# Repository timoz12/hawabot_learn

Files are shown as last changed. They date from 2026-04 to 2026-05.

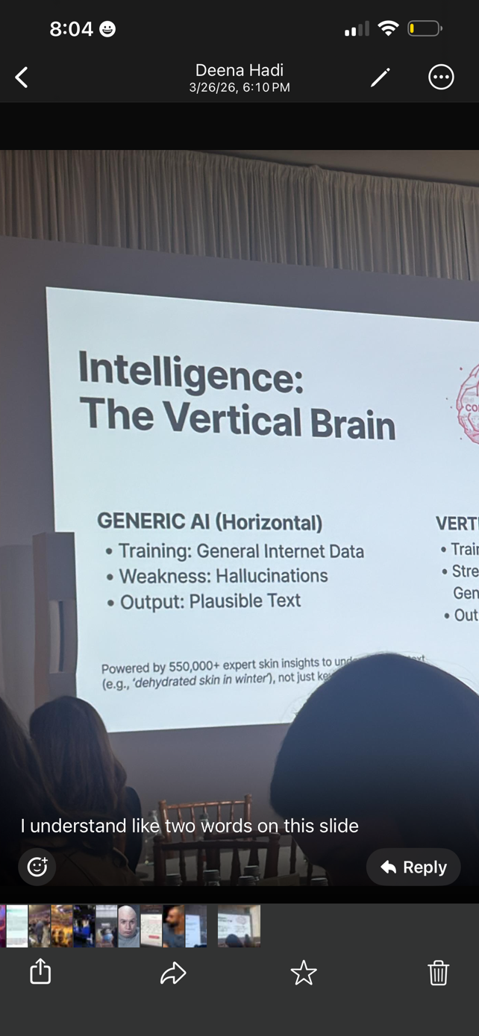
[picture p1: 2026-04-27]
docs/research/IMG_9037.PNG

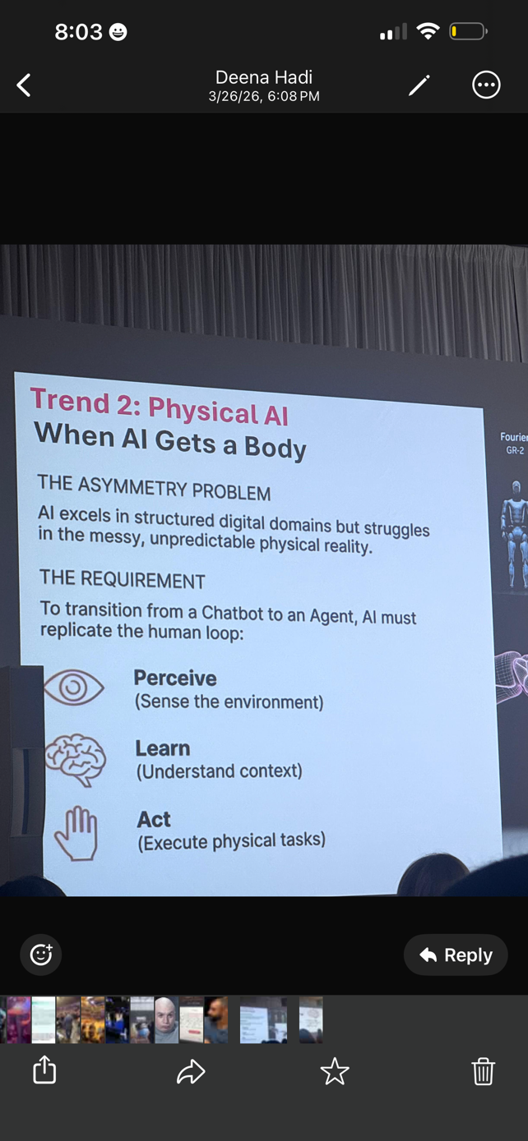
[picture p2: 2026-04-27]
docs/research/IMG_9034.PNG

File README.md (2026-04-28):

# HawaBot

Physical AI robotics platform for kids. Part of [Hawa Labs](https://hawalabs.com).

Kids design a custom robot character, Hawa Labs 3D prints and ships it, then kids code and teach their robot using Python + an AI tutor.

## Project Structure

```
hawabot/                      SDK — Python package shipped with every kit
├── robot.py                  Student entry point
├── character/                Character profiles + animations
├── config/                   Hardware tier definitions (Spark/Core/Pro)
├── joints/                   Body parts (head, arm, waist, leg)
├── drivers/                  Hardware abstraction (mock, pico, pi5)
├── sensors/                  Sensor abstractions
├── sim/                      Simulation engine + 2D visualizer
├── teach.py                  Teach-by-demo (record + playback)
├── curriculum/               Mission loader + progress tracker
├── tutor/                    AI tutor + safety filter
└── studio/                   Streamlit IDE

pipeline/                     Shell pipeline — the moat
├── skeleton.py               Spark skeleton geometry generator
├── shell_pipeline.py         Scale → Subtract → Trim → Validate
├── joint_cuts.py             Joint clearance cuts + section splitting
├── preview.py                3D preview renderer (matplotlib)
├── SKELETON_SPEC.md          Parametric SolidWorks reference
└── skeleton_exports/         SolidWorks parameter files + exported STLs

web/                          Design platform prototype
├── app.py                    Flask backend (Meshy API + pipeline)
└── templates/index.html      Three.js frontend

firmware/                     Microcontroller firmware
└── pico_w/main.py            MicroPython servo controller for Pi Pico W

missions/                     Curriculum content (5 months)
├── month_01/ ... month_05/

docs/                         Documentation
├── STRATEGY.md               Vision, moat, business model
├── COMPETITIVE_ANALYSIS.md   Feature matrix vs competitors
├── ARCHITECTURE.md           Technical architecture
├── IMPLEMENTATION_PLAN.md    Phased build plan
├── GO_TO_MARKET.md           GTM strategy
├── research/                 Original inspiration (slides, papers)
└── reference_robot/          Full-scale Hawabot specs (Poppy URDF, servos)
```

## Quick Start

```bash
python3 -m venv .venv
source .venv/bin/activate
pip install -e ".[sim]"
pip install flask trimesh manifold3d scipy shapely rtree
```

### Run the SDK
```python
from hawabot import Robot

robot = Robot()
robot.head.pan(45)
robot.arm.left.wave()
robot.express("happy")

recording = robot.teach(5)
robot.play(recording)
robot.shutdown()
```

### Run the Design Platform
```bash
python web/app.py
# Open http://localhost:5001
```

### Run the Shell Pipeline
```bash
python -m pipeline.shell_pipeline sculpture.stl skeleton.stl output_shell.stl
```

## Hardware Tiers

| Tier | Form | DOF | Voice | BOM | Price |
|---|---|-----|---|-----|---|
| **Spark** | Tabletop companion | 5 | Buzzer | ~$69 | $99 / $25mo |
| **Core** | Enhanced upper body | 10 | Mic + speaker | ~$200 | $249 / $55mo |
| **Pro** | Full bipedal | 21 | HQ mic + speaker | ~$400 | $499 / $110mo |

## Environment Variables

```bash
HAWABOT_MOCK=1             # Force simulation mode (default)
ANTHROPIC_API_KEY=sk-...   # Required for AI tutor
MESHY_API_KEY=...          # Required for real 3D generation
```

## Hardware Setup (Spark Tier)

To run on real hardware instead of simulation:

```bash
pip install pyserial        # Required for PicoDriver
```

1. Flash MicroPython onto Pi Pico W (hold BOOTSEL, drag `.uf2`)
2. Copy `firmware/pico_w/main.py` to the Pico W (via Thonny or mpremote)
3. Wire servos to GP0-GP4 (see `docs/ARCHITECTURE.md` for pin map)
4. Connect Pico W via USB

```python
from hawabot import Robot
robot = Robot(mock=False)   # Connects to Pico W on /dev/ttyACM0
robot.head.pan(45)          # Physical servo moves!
```

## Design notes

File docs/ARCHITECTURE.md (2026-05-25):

# HawaBot Technical Architecture

## System Overview

HawaBot is composed of five major subsystems that work together to deliver the full experience: design a character, manufacture the physical robot, code it, learn from it, and grow with it.

```
+---------------------+       +---------------------+       +---------------------+
|  DESIGN PLATFORM    |       |  SHELL PIPELINE     |       |  FULFILLMENT        |
|  (web/)             |  -->  |  (pipeline/)        |  -->  |  3D Print + Ship    |
|  Flask + Three.js   |       |  trimesh+manifold3d |       |  (Manual / Partner) |
+---------------------+       +---------------------+       +---------------------+
                                                                      |
                                                                      v
+---------------------+       +---------------------+       +---------------------+
|  AI TUTOR           |  <->  |  SDK                |  <->  |  HARDWARE           |
|  (hawabot/tutor/)   |       |  (hawabot/)         |       |  ESP32-S3 (WiFi→phone)|
|  Claude Haiku+Sonnet|       |  Python package     |       |  Servos + Sensors   |
+---------------------+       +---------------------+       +---------------------+
```

---

## 1. Design Platform (`web/`)

### Purpose

Customer-facing web application where kids design their robot character, preview it in 3D, and purchase a kit.

### Current Implementation

- **Framework:** Flask (Python) with Jinja2 templates
- **3D Viewer:** Three.js with STL loader for interactive preview
- **API Integration:** Meshy API for text-to-3D and image-to-3D generation
- **Pipeline Integration:** Calls shell pipeline directly for real-time preview

### Architecture

```
Browser (Three.js viewer)
    |
    v
Flask App (web/app.py)
    |
    +-- POST /api/generate
    |       |
    |       +-- Meshy API (text/image -> 3D mesh)    [or mock]
    |       +-- Shell Pipeline (mesh -> printable shell)
    |       +-- Joint Cuts (shell -> body sections)
    |       +-- Return section metadata + 3D URLs
    |
    +-- GET /api/model/<id>/<file>
    |       |
    |       +-- Serve STL/GLB files for viewer
    |
    +-- GET /
            |
            +-- Render index.html (design UI + Three.js)
```

### Data Flow: Character Design to Printable Shell

1. Kid enters text prompt or uploads sketch/photo
2. Platform calls Meshy API (~$0.30/generation, Meshy 6 model)
3. Meshy returns 3D mesh (STL, ~500K faces)
4. Shell pipeline processes mesh (see Section 2)
5. Three.js viewer displays shell sections with exploded view
6. Kid selects tier (Spark/Pro) and plan (full/subscription)
7. Order queued for fulfillment

### Production Architecture (Planned)

```
Next.js Frontend (React + Three.js Fiber)
    |
    v
API Layer (Next.js API routes or FastAPI)
    |
    +-- Auth (Clerk or Auth0)
    +-- Payment (Stripe)
    +-- Meshy API (3D generation)
    +-- Pipeline Worker (async shell processing)
    +-- Order DB (PostgreSQL)
    +-- Fulfillment Queue (webhook to print farm)
```

---

## 2. Shell Pipeline (`pipeline/`)

### Purpose

The core technical moat. Converts any arbitrary 3D sculpture mesh into a set of printable shell sections that fit around a standard servo skeleton.

### Pipeline Stages

```
INPUT: sculpture.stl (from Meshy or upload)
  |
  v
[1] SCALE ── scale_skeleton_to_sculpture()
  |   - Center both meshes on same origin
  |   - Scale skeleton uniformly to fit inside sculpture
  |   - Maintain padding_mm (default 3mm) for wall thickness
  |   - Clamp scale factor >= 0.5 (never shrink below 50%)
  |
  v
[2] SUBTRACT ── subtract_skeleton()
  |   - Convert trimesh -> manifold3d Manifold objects
  |   - Boolean difference: sculpture - skeleton
  |   - manifold3d guarantees watertight output
  |   - Convert result back to trimesh
  |
  v
[3] TRIM ── trim_shell()
  |   - Remove degenerate and duplicate faces
  |   - Remove unreferenced vertices
  |   - Split into bodies, discard fragments < 10% of largest
  |   - Concatenate remaining bodies
  |
  v
[4] VALIDATE ── validate_shell()
  |   - Check watertightness
  |   - Measure bounding box dimensions
  |   - Ray-cast wall thickness estimation (500 samples)
  |   - Report: min/avg/max wall thickness, volume, face count
  |   - Printability pass/fail (watertight + no degenerate + min wall >= 1mm)
  |
  v
[5] JOINT CUTS ── cut_joint_clearances()
  |   - Define clearance volumes for each joint's range of motion
  |   - Boolean subtract clearance volumes from shell
  |   - Joints: head pan/tilt, shoulder pitch, waist yaw
  |
  v
[6] SPLIT ── split_shell()
  |   - Cut shell into body sections using half-space intersections
  |   - Sections: head, torso, left_arm, right_arm, base
  |   - Each section is independently watertight
  |
  v
OUTPUT: section_head.stl, section_torso.stl, section_left_arm.stl, etc.
```

### Key Design Decisions

| Decision | Rationale |
|---|---|
| **manifold3d for booleans** | Only library that guarantees watertight output. CGAL is too slow. Trimesh booleans are unreliable on complex meshes. |
| **trimesh for I/O and analysis** | Best Python mesh library for loading, repair, measurement, export. |
| **Scale skeleton, not sculpture** | Preserves character proportions. Skeleton is engineered; sculpture is artistic. |
| **Split into sections** | Required for 3D printing (no support material inside cavities). Also enables magnetic snap-fit assembly. |
| **Magnets for attachment** | 6x2mm N35 neodymium magnets + snap-fit clips. Kid-friendly assembly, no tools required. |

### Skeleton Specification

The skeleton is defined parametrically in `pipeline/skeleton.py` based on the tier's servo dimensions and joint layout.

**Spark Skeleton (7 DOF):**
```
Joint Layout:
  - Head Pan (yaw): SG90, +-90 deg
  - Head Tilt (pitch): SG90, +-45 deg
  - Left Shoulder (pitch): MG90S, +-90 deg
  - Left Shoulder (roll): SG90, +-45 deg
  - Right Shoulder (pitch): MG90S, +-90 deg
  - Right Shoulder (roll): SG90, +-45 deg
  - Waist (yaw): SG90, +-60 deg

Physical Layout:
  [HEAD] ---- head pan servo + tilt servo
    |
  [TORSO] --- shoulder servos (spread = 40mm each side)
    |
  [BASE] ---- waist servo
```

**Pro Skeleton (19 DOF):** Same 250mm frame as Spark, adds elbow pitch and hand pitch per arm plus 8 leg joints (hip yaw, hip pitch, knee pitch, ankle pitch × 2) for walking. Includes FSRs in feet, battery, mic, IMU, and camera.

---

## 3. SDK (`hawabot/`)

### Package Structure

```
hawabot/
  __init__.py          # Exports Robot
  robot.py             # Robot class — main entry point
  config/
    tiers.py           # Tier definitions (Spark/Pro/Max), joint specs
  character/
    profile.py         # CharacterProfile (YAML-based)
    profiles/          # Default character YAML files
    animations.py      # Character-specific animations + expressions
  joints/
    head.py            # Head (pan, tilt, nod, shake)
    arm.py             # Arms (wave, reach, elbow bend)
    waist.py           # Waist (turn)
    leg.py             # Legs (Pro/Max only — walk, balance, kick)
  drivers/
    base.py            # BaseDriver ABC
    mock.py            # MockDriver for simulation
    pico.py            # PicoDriver — serial to Pi Pico W (prototype/legacy)
    pi5.py             # Pi5Driver — Max tier only (future, 400-500mm robot)
    esp32.py           # ESP32Driver — WiFi to ESP32-S3 (Spark/Pro production)
  sensors/             # Ultrasonic, IMU, camera abstractions
  sim/
    engine.py          # SimulationEngine — tracks joint state
    visualizer.py      # Matplotlib-based pose visualization
  teach.py             # Teach-by-demo: record() and playback()
  curriculum/          # Mission validation helpers
  tutor/               # AI tutor integration
  studio/              # Streamlit-based visual tool (optional)
```

### Core Abstractions

#### Robot (Entry Point)

```python
from hawabot import Robot

robot = Robot()                    # Auto-detect tier, load character profile
robot = Robot(tier="spark")        # Force tier
robot = Robot(mock=True)           # Force simulation mode
robot = Robot(character_path="my_character.yaml")
```

The `Robot` class:
- Loads the character profile (YAML) or uses defaults
- Detects hardware tier or falls back to simulation
- Instantiates the appropriate driver (MockDriver, PicoDriver, ESP32Driver, Pi5Driver)
- Creates body part objects (Head, Arms, Waist, optionally Legs)
- Provides high-level methods: `express()`, `teach()`, `play()`, `shutdown()`

#### Driver Abstraction

```
BaseDriver (ABC)
  |
  +-- MockDriver       # Logs commands, simulates joint state
  |
  +-- PicoDriver       # Serial/USB to Pi Pico W (PWM servos) — legacy
  |
  +-- ESP32Driver      # WiFi REST/WS to ESP32-S3 (Spark/Pro production)
  |
  +-- Pi5Driver        # Max tier only (future, 400-500mm)
```

All drivers implement the `BaseDriver` ABC (`hawabot/drivers/base.py`):
- `set_angle(joint_name, angle)` — command a joint to a target angle (degrees)
- `get_angle(joint_name)` — read current angle (degrees)
- `get_temperature(joint_name)` — actuator temperature in °C, or None if unsupported
- `get_voltage()` — supply voltage, or None if unsupported
- `wait(seconds)` — block for animation timing
- `get_event_log()` — ordered list of events for curriculum validation
- `shutdown()` — return all joints to rest and release resources

#### Character Profile System

```yaml
# character.yaml
name: "FireDrake"
tier: "spark"
personality: "brave and curious"
animations:
  happy:
    - {head_tilt: 15, duration: 0.3}
    - {left_shoulder: 45, right_shoulder: 45, duration: 0.5}
  greeting:
    - {head_pan: -30, duration: 0.3}
    - {head_pan: 30, duration: 0.3}
    - {head_pan: 0, left_shoulder: 90, duration: 0.5}
expressions:
  happy: "happy"
  sad: "thinking"
  excited: "greeting"
```

Loaded by `CharacterProfile.load()` using Pydantic for validation. Falls back to default profile if no custom file exists.

#### Teach-by-Demo

```python
# Record
recording = robot.teach(duration=5, sample_rate_hz=20)

# On real hardware (Pro/Max): servos enter compliance mode,
# kid physically moves the robot's arms/head,
# positions are sampled at 20 Hz.

# On simulation: gentle random motion is simulated.

# Playback
robot.play(recording, speed=1.0)

# Save/Load
recording.save("my_dance.json")
loaded = Recording.load("my_dance.json")
robot.play(loaded)
```

The Recording object stores timestamped joint positions as a list of frames. Serialized as JSON with character name and tier metadata.

### Dependencies

| Package | Purpose | Required |
|---|---|---|
| pyyaml | Character profile loading | Yes |
| pydantic | Config validation | Yes |
| matplotlib | Simulation visualization | Optional (`[sim]`) |
| anthropic | AI tutor | Optional (`[tutor]`) |
| streamlit | Visual studio tool | Optional (`[studio]`) |

---

## 4. AI Tutor (`hawabot/tutor/`)

### Architecture

```
Student Input (text)
    |
    v
[SAFETY LAYER] ── Claude Haiku (fast, cheap)
    |   - COPPA compliance check
    |   - PII detection and rejection
    |   - Content appropriateness filter
    |   - No child messages stored
    |
    v  (passes safety check)
[TUTOR LAYER] ── Claude Sonnet (capable, pedagogical)
    |   - System prompt: robotics educator persona
    |   - Mission context injection (current lesson objectives)
    |   - Character-aware ("Let's make FireDrake wave!")
    |   - Socratic method (questions, not answers)
    |   - Code suggestions scoped to SDK
    |
    v
Tutor Response (text + optional code)
```

### V1 Implementation

- **No RAG** — system prompt + mission context injection is sufficient for V1
- **Stateless** — each request includes system prompt + current mission + recent conversation (last 5 turns)
- **Character injection** — tutor references the kid's character name and tier capabilities
- **Guardrails** — tutor only suggests code using the hawabot SDK; does not generate arbitrary Python

### System Prompt Structure (V1)

```
[Role] You are a robotics tutor for a kid using HawaBot.
[Character] The student's robot is named {name}, a {personality} character.
[Tier] The robot is a {tier} with {dof} degrees of freedom.
[Mission] Current mission: {mission_title}. Objectives: {objectives}.
[Pedagogy] Use Socratic method. Ask questions before giving answers.
           Relate concepts to the physical robot. Use the character's name.
[Safety] Never store or request personal information. Keep responses
         age-appropriate. If unsure, redirect to the mission topic.
[SDK] Only suggest code using the hawabot package. Available APIs: {api_list}
```

### Cost Model

| Component | Model | Cost per 1K tokens | Avg tokens/interaction | Cost/interaction |
|---|---|---|---|---|
| Safety | Claude Haiku | $0.25/1M input | ~200 input | $0.00005 |
| Tutor | Claude Sonnet | $3/1M input | ~500 input + 300 output | $0.0024 |
| **Total** | | | | **~$0.003** |

At 50 interactions/student/month: ~$0.15/student/month. Negligible relative to kit price.

---

## 5. Curriculum System (`missions/`)

### Structure

```
missions/
  month_01/           # Joints, DOF, basic motion (Spark+)
  month_02/           # Sensing: ultrasonic, reactions (Pro+)
  month_03/           # Feedback loops, IMU balance (Pro+)
  month_04/           # Computer vision, object tracking (Pro+)
  month_05/           # Robot brain: RL, LLM integration (Pro+)
```

Each month contains 5 missions. Each mission includes:
- **Prompt file** for the AI tutor (mission context, objectives, hints)
- **Starter code** for the student
- **Validation logic** (checks robot event log for expected behaviors)
- **Extension challenges** for advanced students

### Mission Validation

The SDK's event log system allows missions to programmatically verify that a student completed objectives:

```python
# Student code
robot.head.pan(45)
robot.arm.left.wave()

# Validation (run by curriculum system)
log = robot.event_log()
assert any(e["joint"] == "head_pan" and e["angle"] == 45 for e in log)
assert any(e["action"] == "wave" and e["side"] == "left" for e in log)
```

---

## 6. Hardware Abstraction

### Tier Definitions (`hawabot/config/tiers.py`)

Each tier defines:
- Joint names and limits (min/max angle, default speed)
- Servo type per joint
- Compute platform
- Available sensors
- Form factor (tabletop / upper_body / bipedal)

### Communication Protocols

| Tier | Compute | Protocol | Servos |
|---|---|---|---|
| Spark | ESP32-S3 | WiFi | PWM via PCA9685 (SG90/MG90S) |
| Pro | ESP32-S3 | WiFi | PWM (SG90) + Dynamixel bus (XL330) + FSRs |
| Max (future) | Pi 5 / CM5 | Local + WiFi | Dynamixel bus, on-board AI |

### PicoDriver — Spark Tier Hardware (`hawabot/drivers/pico.py`)

> **Note:** PicoDriver is the prototype/legacy driver for Pi Pico W. Production Spark and Pro use ESP32-S3 with WiFi. The ESP32Driver (not yet implemented) will use WiFi + REST/WebSocket API instead of USB serial. See `firmware/esp32_s3/` when available.

The PicoDriver enables the Spark tier by communicating with a Raspberry Pi Pico W over USB serial. The Pico W runs MicroPython firmware that drives PWM signals to 5 hobby servos.

**Architecture (Legacy — Pi Pico W):**

```
Host (laptop)                          Pi Pico W (MicroPython)
  PicoDriver  ─── USB serial ───►  firmware/pico_w/main.py
              ◄── responses ────         │
                                         ├─ GP0  → waist_yaw (SG90)
                                         ├─ GP1  → left_shoulder_pitch (MG90S)
                                         ├─ GP2  → right_shoulder_pitch (MG90S)
                                         ├─ GP3  → head_pan (SG90)
                                         ├─ GP4  → head_tilt (SG90)
                                         └─ GP26 → VSYS ADC (battery voltage, optional)
```

**Architecture (Production — ESP32-S3):**

```
Phone/Tablet (app)                     ESP32-S3 (on robot)
  AI Tutor    ─── WiFi REST/WS ───►  Custom PCB (55×35mm)
  Voice AI    ◄── sensor streams ──        │
  Curriculum                               ├─ I2C → PCA9685 → 7-19 PWM servos
                                           ├─ I2S → MAX98357A → speaker
                                           ├─ PDM ← SPH0641LU4H-1 ← mic (Pro)
                                           ├─ I2C → MPU6050 IMU (Pro)
                                           ├─ FSRs in feet (Pro)
                                           ├─ Camera (Pro)
                                           ├─ Battery (Pro)
                                           └─ USB-C power
```

**Serial Protocol (115200 baud, newline-terminated text):**

| Command | Response | Description |
|---|---|---|
| `S <pin> <pulse_us>` | `OK` | Set servo PWM pulse width |
| `V` | `V <float>` or `V NONE` | Read supply voltage via ADC |
| `P` | `PONG` | Ping / health check |

**PWM Calibration:**

Hobby servos (SG90/MG90S) accept 500–2500 µs pulses at 50 Hz:
- -90° → 500 µs
- 0° (centre) → 1500 µs
- +90° → 2500 µs
- Linear mapping: `pulse_us = 1500 + (angle / 90) * 1000`

**Key Design Decisions:**

| Decision | Rationale |
|---|---|
| Track angles locally (no servo feedback) | SG90/MG90S have no position readback; store last-commanded angle |
| Simple text protocol | Easy to debug via serial monitor; MicroPython-friendly |
| Ping handshake on connect | Detects firmware issues immediately rather than failing on first command |
| Configurable pin map | Same driver works with alternative wiring; defaults match reference design |

**Firmware Installation:**

1. Flash MicroPython onto Pi Pico W (hold BOOTSEL, drag `.uf2` file)
2. Copy `firmware/pico_w/main.py` as `main.py` on the Pico W filesystem (via Thonny, mpremote, or rshell)
3. Power-cycle — firmware starts listening on USB serial immediately

### Sensor Abstraction

```
sensors/
  ultrasonic.py    # HC-SR04 (future): distance measurement
  imu.py           # MPU6050 (Pro+): orientation, acceleration
  fsr.py           # FSRs in feet (Pro+): ground contact, balance feedback
  camera.py        # Camera (Pro+): image capture, video stream
  microphone.py    # Mic (Pro+): audio capture for voice AI
```

---

## 7. Data Flow Diagrams

### End-to-End: Design to Learning

```
[Kid designs character] --> [Meshy API generates 3D] --> [Shell pipeline processes]
         |                                                        |
         v                                                        v
[Preview in browser]                                [STL files queued for printing]
         |                                                        |
         v                                                        v
[Select tier + purchase]                            [3D print + assemble + ship]
         |                                                        |
         v                                                        v
[Character profile YAML]  <----  [Kit arrives]  ---->  [Install SDK: pip install hawabot]
         |                            |                           |
         v                            v                           v
[AI tutor loaded with      [Physical robot assembled]    [from hawabot import Robot]
 character context]                   |                           |
         |                            v                           v
         +----------->  [Curriculum missions begin]  <-----------+
```

### Runtime: Student Coding Session

```
Student Python Script
    |
    +-- import hawabot
    |
    +-- Robot() instantiation
    |       +-- Load character profile (YAML)
    |       +-- Detect/select tier
    |       +-- Initialize driver (Mock/Pico/ESP32/Pi5)
    |       +-- Build body parts (Head, Arms, Waist, Legs)
    |
    +-- robot.head.pan(45)
    |       +-- Driver.set_angle("head_pan", 45)
    |       +-- [Mock]: clamp angle, update state dict, log event
    |       +-- [Pico]: clamp angle → pulse_us → serial "S <pin> <us>" → PWM → servo moves
    |       +-- [Pi5]: clamp angle → UART packet → smart servo moves
    |
    +-- robot.express("happy")
    |       +-- Look up animation in character profile
    |       +-- Play sequence of joint movements
    |
    +-- robot.teach(5)
            +-- [Real]: enable compliance mode on smart servos
            +-- Record joint positions at 20 Hz for 5 seconds
            +-- Return Recording object
```

---

## 8. Deployment Architecture

### Current (Prototype)

- SDK: `pip install -e ".[sim]"` from local clone
- Web: `python web/app.py` on localhost
- Pipeline: CLI invocation
- AI Tutor: requires `ANTHROPIC_API_KEY` env var
- Robot firmware: MicroPython on Pi Pico W (legacy) or ESP-IDF on ESP32-S3 (production target)

### Production (Planned)

```
                    +-------------------+
                    |   CDN (Vercel)    |
                    |   Next.js SSR     |
                    +--------+----------+
                             |
                    +--------v----------+
                    |   API Gateway     |
                    |   (Vercel/AWS)    |
                    +--------+----------+
                             |
        +--------------------+--------------------+
        |                    |                    |
+-------v-------+   +-------v-------+   +-------v-------+
| Meshy Worker  |   | Auth + Payment|   | Tutor API     |
| (async queue) |   | (Stripe/Clerk)|   | (Claude API)  |
+-------+-------+   +---------------+   +---------------+
        |
+-------v-------+
| Shell Pipeline |
| (compute node) |
+-------+-------+
        |
+-------v-------+
| Order + Print  |
| Queue (DB)     |
+----------------+
```

### Environment Variables

| Variable | Purpose | Required |
|---|---|---|
| `HAWABOT_MOCK` | Force simulation mode (default: "1") | No |
| `ANTHROPIC_API_KEY` | Claude API for AI tutor | For tutor features |
| `MESHY_API_KEY` | Meshy API for 3D generation | For design platform |

---

## 9. Technology Stack Summary

| Layer | Technology | Status |
|---|---|---|
| SDK Core | Python 3.10+, PyYAML, Pydantic | Built |
| SDK Simulation | matplotlib | Built |
| Shell Pipeline | trimesh, manifold3d, scipy, numpy | Built |
| Joint Cuts | trimesh, manifold3d | Built |
| Web Prototype | Flask, Three.js, Jinja2 | Built |
| AI Tutor | Anthropic Claude API (Haiku + Sonnet) | Scaffolded |
| Curriculum | YAML mission definitions + Python validation | Scaffolded |
| PicoDriver (legacy) | pyserial, MicroPython PWM firmware | Built (prototype only) |
| ESP32Driver (Spark/Pro) | WiFi REST/WS to ESP32-S3 | Planned |
| Pi5Driver (Max future) | Pi 5 UART/TTL for Dynamixel servos | Stub only |
| Production Web | Next.js, React, Three.js Fiber | Planned |
| Payment | Stripe | Planned |
| Auth | Clerk or Auth0 | Planned |
| Database | PostgreSQL | Planned |
| Hosting | Vercel + AWS Lambda | Planned |

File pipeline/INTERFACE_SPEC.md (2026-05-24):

# HawaBot Shell Interface Specification

This document defines the **contract between the skeleton and the shell parts**. It specifies where shells attach, how they're oriented, what clearance they need, and where cut planes divide a character into body zones.

The skeleton team owns this spec. The shell pipeline must conform to it. If you change a magnet position here, both the skeleton CAD and the shell pipeline must update.

---

## Body Zones

A character model gets dissected into **5 zones**. Each zone becomes a separate hollow shell that snaps onto the skeleton via magnets.

```
    ┌─────────────┐
    │             │
    │    HEAD     │  Zone 1
    │             │
    ├──┬──────┬───┤  ← Head cut plane
    │  │      │   │
 ┌──┤  │TORSO │  ├──┐
 │L │  │      │  │R │
 │ARM│ │      │  │ARM│  Zone 3 (L), Zone 4 (R)
 │  │  │      │  │  │
 └──┤  │      │  ├──┘
    │  │      │   │  Zone 2
    ├──┴──────┴───┤  ← Base cut plane
    │    BASE     │  Zone 5
    └─────────────┘
```

| Zone | Name | What it covers | Attaches to |
|---|---|---|---|
| 1 | Head | Head + neck | Head magnet ring on skeleton |
| 2 | Torso | Chest, back, waist | Torso magnet grid on skeleton |
| 3 | Left Arm | Left shoulder + arm | Left arm magnets on skeleton |
| 4 | Right Arm | Right shoulder + arm | Right arm magnets on skeleton |
| 5 | Base | Feet, base cover | Base rim magnets on skeleton |

---

## Cut Planes

Cut planes define where the character model gets sliced into zones. The customer can **adjust these up/down** during the guided dissection step to match their character's proportions.

### Default Cut Plane Positions

| Cut Plane | Z Position | Adjustable Range | Divides |
|---|---|---|---|
| Head / Torso | Z = 115 mm | 105–130 mm | Head zone from torso zone |
| Torso / Base | Z = 10 mm | 0–20 mm | Torso zone from base zone |
| Left arm | X = -28 mm | -24 to -35 mm | Left arm from torso |
| Right arm | X = +28 mm | +24 to +35 mm | Right arm from torso |

### Cut Plane Rules

1. **Head/Torso cut** must be **below** the head pan servo (Z=120) so the pan/tilt stack stays inside the head shell. Default Z=115 is at the neck area — the head shell drops over the pan/tilt servo stack.
2. **Arm cuts** are vertical planes. They must be **inboard of the shoulder servo** (X=±40) so the servo housing stays with the skeleton.
3. **Torso/Base cut** must be **above the base plate top surface** (Z=0). The base shell wraps around the base plate sides and bottom.
4. All cuts produce **overlapping edges** — each shell extends 1mm past the cut plane to avoid visible gaps when assembled.

### Customer Adjustment UI

The customer sees the character model with colored cut lines. They can drag each line:

- **Head cut:** Slide up/down to adjust where the neck meets the body. Higher = more neck on the torso piece. Lower = more neck on the head piece.
- **Arm cuts:** Slide in/out to adjust how much shoulder is on the arm vs torso piece.
- **Base cut:** Slide up/down to control how much of the lower body is torso vs base.

Software validates after each adjustment that:
- No cut plane intersects a servo location
- Each zone has minimum 15mm height/width (printability)
- Magnet positions fall within the correct zone

---

## Clearance Envelopes

Each zone shell must maintain **minimum clearance** from the skeleton so it can be placed/removed and joints can move.

### Head Zone Clearance

```
Shell inner surface must clear:
- Head pan servo body by ≥ 2mm radially
- Head tilt servo body by ≥ 2mm radially  
- Head pan rotation: ±90° yaw → shell must not collide with torso shell
  → minimum inner radius of 18mm around Z axis at cut plane
- Head tilt rotation: ±30° pitch → clearance arc in +Y/-Y direction
  → 5mm gap between tilt servo horn and shell inner wall
```

| Constraint | Value | Why |
|---|---|---|
| Min inner radius at neck | 18 mm | Pan rotation clearance |
| Min gap from tilt servo | 5 mm | Nod range of motion |
| Min shell wall thickness | 2.0 mm | Printability |
| Opening diameter (bottom) | ≥ 36 mm | Must fit over head magnet ring |

### Torso Zone Clearance

```
Shell inner surface must clear:
- Torso column by ≥ 3mm radially (wire routing space)
- Waist rotation: ±90° → the entire torso shell rotates with the waist servo
  → at the base cut plane, shell must clear base shell by ≥ 2mm through full rotation
- Shoulder servo housing by ≥ 2mm
```

| Constraint | Value | Why |
|---|---|---|
| Min gap from torso column | 3 mm | Wire routing + tolerance |
| Min gap at waist rotation | 2 mm | Shell-to-shell clearance during rotation |
| Min shell wall thickness | 2.0 mm | Printability |

### Arm Zone Clearance

```
Shell inner surface must clear:
- Shoulder servo housing by ≥ 2mm
- Shoulder pitch rotation: ±90° → arm shell rotates around X axis
  → at the shoulder cut, shell must clear torso shell through full rotation
- Servo horn + arm shaft by ≥ 2mm
```

| Constraint | Value | Why |
|---|---|---|
| Min gap from servo housing | 2 mm | Assembly tolerance |
| Min inner radius at shoulder | 20 mm | Rotation clearance |
| Min shell wall thickness | 2.0 mm | Printability |
| Max arm shell weight | 15 g | Servo torque limit (MG90S: 1.8 kg·cm) |

### Base Zone Clearance

```
Shell covers the base plate sides and bottom.
- Must clear USB-C port (slot in +X side)
- Must not block base plate top surface (waist servo mounts here)
- Battery compartment access (future)
```

| Constraint | Value | Why |
|---|---|---|
| USB-C port clearance | 10×4 mm opening on +X face | ESP32-S3 PCB USB-C access |
| Min shell wall thickness | 2.0 mm | Printability |
| Max overhang past base | 5 mm | Stability — shell shouldn't make it tippy |

---

## Magnet Interface Contract

### How It Works

1. **Skeleton** has magnet pockets at all predefined positions (see SKELETON_SPEC.md § Magnet Grid)
2. **Software** analyzes the shell geometry and selects which magnet positions to use
3. **Shell** gets magnet boss features merged onto its inner surface at the selected positions
4. **Assembly:** magnets press-fit into both skeleton and shell pockets. User drops shell onto skeleton — magnets snap it into place.

### Magnet Boss Geometry (Shell Side)

Each magnet boss is a small cylindrical protrusion on the shell's inner surface:

```
        ┌─────────┐  Shell outer wall
        │         │
        │  ┌───┐  │  Magnet boss: ⌀10mm base, ⌀6.1mm pocket
        │  │ M │  │  M = magnet pocket (⌀6.1 × 3.1mm deep)
        │  └───┘  │
        │         │
        └─────────┘

Side view:
        Shell wall (2mm)
        ├──┤
             Boss (4mm tall, ⌀10mm)
             ├────┤
                   Pocket (⌀6.1, 3.1mm deep)
                   ├───┤
```

| Parameter | Value | Notes |
|---|---|---|
| Boss outer ⌀ | 10 mm | Structural base |
| Boss height | 4 mm | Extends inward from shell wall |
| Pocket ⌀ | 6.1 mm | Press-fit for 6mm magnet |
| Pocket depth | 3.1 mm | Flush or 0.1mm recessed |
| Min shell wall behind boss | 1.5 mm | Don't punch through |

### Magnet Selection Algorithm

For each body zone, the software:

1. **Filters** magnet positions to those where the shell has ≥ 6mm wall thickness (boss needs 4mm + 2mm wall behind it)
2. **Scores** each position by:
   - Distance from shell center of mass (favor positions that create balanced pull)
   - Angular distribution (favor even spacing, penalize clustering)
   - Proximity to shell edge (penalize positions too close to zone boundary)
3. **Selects** minimum required magnets per zone:

| Zone | Min Magnets | Max Magnets | Required Pattern |
|---|---|---|---|
| Head | 3 | 8 | At least 3, evenly distributed around ring |
| Torso | 4 | 10 | At least 2 front + 2 back for rotational stability |
| Left Arm | 2 | 6 | At least 1 near shoulder + 1 toward hand |
| Right Arm | 2 | 6 | Mirror of left |
| Base | 3 | 8 | At least 3 corners for stability |

4. **Validates** that selected magnets provide:
   - Pull force ≥ 2× shell weight (each magnet ~0.5kg, so 3 magnets hold 1.5kg — plenty for ~15g shells)
   - No single-axis alignment (magnets can't all be in a line)
   - Stable seating (shell doesn't rock when placed)

### Polarity Convention

| Side | Polarity Facing Out |
|---|---|
| Skeleton | North |
| Shell | South |

All magnets in a zone face the same direction. This means any shell fits any skeleton — no per-character polarity matching needed.

---

## Assembly Sequence (End User)

1. Skeleton ships assembled — servos installed, magnets press-fit, ESP32-S3 PCB wired
2. Customer receives 5 printed shell parts (head, torso, L arm, R arm, base)
3. Customer presses magnets into shell boss pockets (or pre-installed at fulfillment)
4. **Base shell:** Slide onto base plate bottom → magnets snap
5. **Torso shell:** Lower over torso column → magnets snap to column surface
6. **Arm shells:** Slide over shoulder housings → magnets snap
7. **Head shell:** Drop over head servo stack → magnets snap to neck ring
8. Power on, code, play

No tools required. All connections are magnetic snap-fit.

---

## Validation Checks (Shell Pipeline Must Pass)

Before a shell set is approved for printing:

| Check | Criteria | Fail Action |
|---|---|---|
| Wall thickness | ≥ 2mm everywhere | Flag thin spots, suggest thickening |
| Clearance | Meets envelope constraints above | Flag interference, suggest hollowing more |
| Magnet bosses | ≥ min count per zone, all have wall behind them | Adjust selection or flag to customer |
| Joint motion | No shell-to-shell collision through full ROM | Trim interfering regions |
| Watertight | Each shell is manifold (printable) | Auto-repair or flag |
| Weight | Each zone ≤ max weight for its servo | Suggest thinner walls or smaller design |
| Opening size | Shell can physically fit over skeleton features | Flag if opening too narrow |

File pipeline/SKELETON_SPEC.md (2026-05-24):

# HawaBot Skeleton — Mechanical Frame Specification

> **NOTE:** This spec is partially stale. The canonical skeleton specification is now maintained in:
> `pipeline/skeleton_exports/solidworks_package/PARAMETRIC_PIPELINE_PLAN.md`
>
> Key changes since this doc was written:
> - Height: 250mm (was 200mm), 325mm foot-to-head with legs
> - DOF: 19 (was 5) — v17 macro with Poppy-informed proportions
> - Servos: SG90 + MG90S + XL330 (was SG90 + MG90S only)
> - Shoulder roll added, waist roll removed
> - MCU: ESP32-S3 (was Pi Pico W)
>
> Refer to PARAMETRIC_PIPELINE_PLAN.md for current joint positions, mate table, and axis architecture.

The skeleton is a **standalone mechanical frame** — a functional robot that moves on its own. Custom character shells snap on via magnets. This spec defines the frame only. See `INTERFACE_SPEC.md` for how shells attach and `SHELL_PIPELINE_SPEC.md` for the customer workflow.

---

## Design Principles

1. **The skeleton is a complete robot.** Power it up, it moves. No shell required.
2. **One skeleton, infinite characters.** Shells are swappable — same frame, different look.
3. **Fixed size, humanoid proportions.** 250mm scale, Poppy Humanoid-informed proportions. Future Pro variant is 400-500mm.
4. **Magnets everywhere, use what you need.** The frame has more magnet seats than any single shell requires. Software picks the best subset per character.

---

## Fixed Dimensions — Spark/Pro Skeleton (v17)

**Target height:** 250mm (base to head top ~210mm above origin, foot bottom at -115mm)
**Proportion:** Poppy Humanoid-inspired (leg ratio 35%, arm ratio 33%)

### Coordinate System

- Origin: center of base plate top surface
- +Z up, +X right (robot's perspective), +Y forward
- All dimensions in millimeters

---

## Bill of Materials

| Component | Qty | Purpose |
|---|---|---|
| SG90 Micro Servo | 3 | Waist yaw, head pan, head tilt |
| MG90S Metal Gear Servo | 2 | Left shoulder, right shoulder |
| Raspberry Pi Pico W | 1 | Controller |
| 6×3mm Neodymium Disc Magnets | ~40 | Shell attachment (skeleton side) |
| M2×5mm Self-Tapping Screws | ~20 | Servo mounting, structural |
| 3D Printed Frame (PLA/PETG) | 1 | Structural body |

---

## Component Dimensions

### SG90 Micro Servo (×3: waist, head pan, head tilt)

| Dimension | Value | Symbol |
|---|---|---|
| Body L (front-back) | 22.7 mm | `SG90_L` |
| Body W (side-side) | 12.2 mm | `SG90_W` |
| Body H (bottom to case top) | 27.0 mm | `SG90_H` |
| Overall H (bottom to spline top) | 32.3 mm | `SG90_H_total` |
| Tab-to-tab length | 32.3 mm | `SG90_tab_L` |
| Tab thickness | 2.8 mm | `SG90_tab_T` |
| Tab underside from bottom | 17.0 mm | `SG90_tab_Z` |
| Mounting hole ⌀ | 2.0 mm | `SG90_hole_D` |
| Mounting hole inset from tab edge | 2.0 mm | `SG90_hole_inset` |
| Shaft center from front face | 6.2 mm | `SG90_shaft_offset` |
| Spline OD | 4.8 mm | `SG90_spline_OD` |
| Turret height above body | 5.96 mm | `SG90_turret_H` |
| Turret ⌀ | 11.8 mm | `SG90_turret_D` |
| Weight | 9 g | — |

### MG90S Metal Gear Servo (×2: shoulders)

| Dimension | Value | Symbol |
|---|---|---|
| Body L | 22.8 mm | `MG90S_L` |
| Body W | 12.4 mm | `MG90S_W` |
| Body H | 28.4 mm | `MG90S_H` |
| Overall H | 32.5 mm | `MG90S_H_total` |
| Tab-to-tab length | 32.1 mm | `MG90S_tab_L` |
| Tab thickness | 2.8 mm | `MG90S_tab_T` |
| Tab underside from bottom | 18.5 mm | `MG90S_tab_Z` |
| Mounting hole ⌀ | 2.0 mm | `MG90S_hole_D` |
| Spline OD | 4.8 mm | `MG90S_spline_OD` |
| Weight | 13.4 g | — |

### Raspberry Pi Pico W

| Dimension | Value | Symbol |
|---|---|---|
| Board L | 51 mm | `PICO_L` |
| Board W | 21 mm | `PICO_W` |
| Board thickness | 1 mm | `PICO_T` |
| Component height (total) | 3.9 mm | `PICO_H_component` |
| Mounting hole ⌀ | 2.1 mm | `PICO_hole_D` |
| Mounting hole spacing (L) | 47.0 mm | `PICO_hole_L` |
| Mounting hole spacing (W) | 11.4 mm | `PICO_hole_W` |
| Hole center from short edge | 2.0 mm | `PICO_hole_edge` |

### 6×3mm Neodymium Disc Magnet

| Dimension | Value | Symbol |
|---|---|---|
| Diameter | 6.0 mm | `MAG_D` |
| Height | 3.0 mm | `MAG_H` |
| Pocket ⌀ (press-fit) | 6.1 mm | `MAG_POCKET_D` |
| Pocket depth | 3.1 mm | `MAG_POCKET_H` |
| Pull force (each) | ~0.5 kg | — |

---

## Frame Assembly Layout

```
                    ┌─────┐
                    │TILT │ SG90  Z=148   shaft→+Y (nod)
                    │ SRV │
                    ├─────┤
                    │ PAN │ SG90  Z=120   shaft→+Z (yaw)
                    │ SRV │
    ┌───────┐       ├─────┤       ┌───────┐
    │ L ARM │ MG90S │     │ MG90S │ R ARM │
    │  SRV  │ Z=110 │     │ Z=110 │  SRV  │
    └───┤   │ X=-40 │     │ X=+40 │   ├───┘
        │   │       │TORSO│       │   │
        │horn       │COLUMN       │horn
                    │  ⌀24│
                    ├─────┤
                    │WAIST│ SG90  Z=10    shaft→+Z (yaw)
                    │ SRV │
              ══════╧═════╧══════
              │     BASE PLATE    │  90×70×20mm
              │  ┌──────────────┐ │
              │  │  Pi Pico W   │ │  Z=-4 (inside base)
              │  │  (X=+25)     │ │
              │  └──────────────┘ │
              └───────────────────┘
```

### Servo Positions

| Servo | Center Position | Orientation | Joint |
|---|---|---|---|
| Waist | (0, 0, 10) | Shaft +Z | Yaw — rotates upper body |
| Left shoulder | (-40, 0, 110) | Shaft -X (outward) | Pitch — raise/lower arm |
| Right shoulder | (40, 0, 110) | Shaft +X (outward) | Pitch — raise/lower arm |
| Head pan | (0, 0, 120) | Shaft +Z | Yaw — turn head L/R |
| Head tilt | (0, 0, 148) | Shaft +Y (forward) | Pitch — nod head |

### Joint Ranges

| Joint | Axis | Range | Notes |
|---|---|---|---|
| Waist yaw | Z | ±90° | Full left/right body rotation |
| Left shoulder pitch | X | ±90° | Arm up/down |
| Right shoulder pitch | X | ±90° | Arm up/down |
| Head pan | Z | ±90° | Head turn left/right |
| Head tilt | Y | -30° to +30° | Head nod up/down |

---

## Structural Frame

The frame is 3D printed as a **single part** (not sectioned — the skeleton doesn't split). Only the cosmetic shells are split into body zones.

### Base Plate

| Parameter | Value | Notes |
|---|---|---|
| Width | 90 mm | Stability footprint |
| Depth | 70 mm | |
| Height | 20 mm | Contains Pico cavity (12mm) + 5mm floor + 3mm top |
| Corner radius | 6 mm | |
| Pico cavity | 57×25×12 mm | Centered at X=+25, cut from bottom |
| USB slot | 14mm wide | Extends from Pico cavity to +X edge |

### Torso Column

| Parameter | Value | Notes |
|---|---|---|
| Cross-section | ⌀24mm (or 24×24 rounded rect) | Central post |
| Height | Z=0 to Z=120 | Base surface to head pan |
| Wire channel | ⌀6mm, offset from center | Runs full height |

### Servo Mounting

Each servo is held by its mounting tabs — two M2 screws through the tab holes into screw bosses printed into the frame. The frame provides:

- **Tab ledge:** horizontal shelf the tab rests on
- **Screw bosses:** cylindrical posts (⌀4mm, with ⌀2mm pilot hole) rising from the ledge
- **Body pocket:** cavity matching servo body dimensions + 0.3mm clearance per side
- **Turret clearance:** open space above servo for turret + shaft + horn rotation
- **Cable exit:** slot in pocket wall for servo wire to reach wire channel

---

## Magnet Grid — Skeleton Side

The skeleton has magnet seats at **predefined positions** on its outer surfaces. Not all are used for every shell — the software selects the optimal subset per character design.

Magnets are press-fit into ⌀6.1mm × 3.1mm pockets printed into the frame surface. **Polarity matters** — all skeleton magnets in a given zone face the same way (N-out) so any matching shell magnet (S-out) will attract.

### Head Zone Magnets

Ring of seats around the neck post, just above the head pan servo. Shells drop over this ring.

| ID | Position | Notes |
|---|---|---|
| H1 | (0, -14, 125) | Front |
| H2 | (0, +14, 125) | Back |
| H3 | (-14, 0, 125) | Left |
| H4 | (+14, 0, 125) | Right |
| H5 | (-10, -10, 125) | Front-left |
| H6 | (+10, -10, 125) | Front-right |
| H7 | (-10, +10, 125) | Back-left |
| H8 | (+10, +10, 125) | Back-right |

**8 positions**, ring radius ≈14mm at Z=125 (just above pan servo top, below tilt servo).

### Torso Zone Magnets

Distributed around the torso column surface. Shells wrap around this.

| ID | Position | Notes |
|---|---|---|
| T1 | (0, -14, 30) | Front, lower |
| T2 | (0, +14, 30) | Back, lower |
| T3 | (0, -14, 70) | Front, mid |
| T4 | (0, +14, 70) | Back, mid |
| T5 | (0, -14, 100) | Front, upper |
| T6 | (0, +14, 100) | Back, upper |
| T7 | (-14, 0, 30) | Left, lower |
| T8 | (+14, 0, 30) | Right, lower |
| T9 | (-14, 0, 70) | Left, mid |
| T10 | (+14, 0, 70) | Right, mid |
| T11 | (-14, 0, 100) | Left, upper |
| T12 | (+14, 0, 100) | Right, upper |

**12 positions**, 3 rings of 4 along torso height.

### Left Arm Zone Magnets

On the arm housing outer surface. Shell sleeve slides over.

| ID | Position | Notes |
|---|---|---|
| LA1 | (-40, -10, 110) | Front |
| LA2 | (-40, +10, 110) | Back |
| LA3 | (-40, 0, 100) | Bottom |
| LA4 | (-40, 0, 120) | Top |
| LA5 | (-52, -8, 110) | Outer front |
| LA6 | (-52, +8, 110) | Outer back |

**6 positions** per arm.

### Right Arm Zone Magnets

Mirror of left arm across YZ plane.

| ID | Position | Notes |
|---|---|---|
| RA1–RA6 | Mirror of LA1–LA6 at +X | Same layout, mirrored |

### Base Zone Magnets

Around the base plate rim. Base cover snaps onto bottom/sides.

| ID | Position | Notes |
|---|---|---|
| B1 | (-35, -28, -10) | Front-left |
| B2 | (+35, -28, -10) | Front-right |
| B3 | (-35, +28, -10) | Back-left |
| B4 | (+35, +28, -10) | Back-right |
| B5 | (0, -28, -10) | Front-center |
| B6 | (0, +28, -10) | Back-center |
| B7 | (-40, 0, -10) | Left-center |
| B8 | (+40, 0, -10) | Right-center |

**8 positions** around the base perimeter at Z=-10 (midway down the base plate side).

### Magnet Summary

| Zone | Count | Total |
|---|---|---|
| Head | 8 | 8 |
| Torso | 12 | 12 |
| Left Arm | 6 | 6 |
| Right Arm | 6 | 6 |
| Base | 8 | 8 |
| **Total** | | **40** |

---

## Wire Routing

| Route | Path | Channel ⌀ |
|---|---|---|
| Pico → Waist servo | Through base plate, up to waist | 6mm |
| Waist → Torso | Vertical channel in torso column | 6mm |
| Torso → Left shoulder | Horizontal branch at Z=110 | 6mm |
| Torso → Right shoulder | Horizontal branch at Z=110 | 6mm |
| Torso → Head pan | Vertical channel continues to Z=120 | 6mm |
| Head pan → Head tilt | Short run between stacked servos | 4mm |

All servo cables route to the Pico's GPIO pins inside the base. Total cable count: 5 servos × 3 wires = 15 wires, bundled into the 6mm channels.

---

## Fabrication Notes

- **Print orientation:** Base plate flat on bed, torso column vertical
- **Material:** PLA for prototyping, PETG for production (better layer adhesion for screw bosses)
- **Layer height:** 0.2mm
- **Infill:** 30% for structural areas, 100% for screw boss zones
- **Supports:** Needed for shoulder overhangs and horizontal wire channels
- **Magnet insertion:** Press-fit during print (pause at magnet pocket layer) or glue after
- **Servo installation:** Drop servos into pockets, secure with M2 screws through tabs

---

## CadQuery Generation

Run `python3 pipeline/generate_skeleton_step.py` (requires CadQuery) to generate the frame as a STEP file for import into SolidWorks or any CAD tool.

The generated file is at `pipeline/skeleton_exports/hawabot_spark_skeleton.step`.

---

## Future Skeleton Variants

| Variant | Use Case | Key Differences |
|---|---|---|
| **Spark Humanoid** (this doc) | Action figures, human characters | Standard proportions |
| **Spark Stumpy** | Dragons, animals, creatures | Wider base, shorter torso, 4 limb mounts |
| **Max Humanoid** | 400-500mm flagship | XL330+XL430, on-board AI (Pi 5/CM5) |

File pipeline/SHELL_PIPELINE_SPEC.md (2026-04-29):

# HawaBot Shell Pipeline — Customer Workflow Specification

End-to-end flow from character idea to printable shell parts.

---

## Overview

```
┌──────────────┐    ┌──────────────┐    ┌──────────────┐    ┌──────────────┐
│  1. DESIGN   │ →  │  2. PREVIEW  │ →  │  3. PURCHASE │ →  │  4. GENERATE │
│  Upload/draw │    │  2D renders  │    │  Confirm +   │    │  3D model    │
│  character   │    │  (cheap)     │    │  pay         │    │  (expensive) │
└──────────────┘    └──────────────┘    └──────────────┘    └──────────────┘
                                                                    │
                                                                    ▼
┌──────────────┐    ┌──────────────┐    ┌──────────────┐    ┌──────────────┐
│  8. PRINT +  │ ←  │  7. EXPORT   │ ←  │  6. FINALIZE │ ←  │  5. DISSECT  │
│  SHIP        │    │  Print-ready │    │  Hollow +    │    │  Guided cuts │
│              │    │  STL files   │    │  magnets     │    │  (customer)  │
└──────────────┘    └──────────────┘    └──────────────┘    └──────────────┘
```

---

## Step 1: Design — Character Input

**Goal:** Customer provides a character concept.

### Input Methods

| Method | Description | Cost | Quality |
|---|---|---|---|
| Photo upload | Customer uploads photo/drawing of character | Free | Depends on source |
| Text prompt | "A samurai cat with a red cape" | Free | AI-dependent |
| Template | Pick from preset character base + customize | Free | Consistent |

### Output
- Character concept stored as image(s) + text description
- Used as input for preview generation

---

## Step 2: Preview — 2D Reference Views

**Goal:** Show the customer what their character will look like before committing to expensive 3D generation.

### Process
1. Generate **4 reference views** from the concept: front, back, left side, right side
2. Use cheapest available model (image-to-image, ~$0.01-0.05 per set)
3. Overlay skeleton silhouette on the views so customer can see proportions
4. Show cut plane lines on the views (dashed lines where dissection will happen)

### Customer Actions
- Approve the look → proceed to purchase
- Adjust → re-generate views (free, can iterate)
- Abandon → no cost incurred

### Technical Notes
- Skeleton silhouette overlay is a fixed SVG/PNG per view angle
- Cut plane lines are drawn at default positions from INTERFACE_SPEC
- No 3D computation at this stage — purely 2D image work

---

## Step 3: Purchase — Confirmation + Payment

**Goal:** Customer commits and pays.

### What They're Buying
- 3D model generation (compute cost)
- 5 printed shell parts (material + printing + shipping)
- Access to their character in the HawaBot app

### Pricing Model
(Defined elsewhere — this spec just covers the technical pipeline)

---

## Step 4: Generate — 3D Model Creation

**Goal:** Turn the 2D concept into a watertight 3D mesh.

### Process
1. **Enforce T-pose:** All generation prompts include T-pose instructions ("arms straight out to sides, legs shoulder-width apart, facing forward"). This is mandatory for clean zone dissection.
2. Send reference views + text description to 3D generation API (Tripo3D primary, Meshy fallback)
3. Receive raw 3D mesh (GLB/OBJ/STL)
4. **Auto-processing:**
   - Scale to match skeleton height (200mm total)
   - Center on origin
   - Orient: +Z up, +Y forward, character facing -Y
   - Repair mesh: close holes, remove degenerate faces, ensure manifold
   - Validate T-pose: check arm zones are ≥15mm wide at cut planes
   - Remesh to uniform triangle size if needed

### T-Pose Enforcement

All character models must be in **T-pose** for the pipeline to produce clean cuts:

| Input Method | T-Pose Enforcement |
|---|---|
| Text-to-3D | System pre-prompt: "standing in T-pose, arms straight out to sides, legs apart" |
| Image-to-3D | If source image isn't T-pose, regenerate reference views in T-pose first |
| Uploaded STL | Detect arm angle; if not T-pose, flag and offer to regenerate |

### Output
- Watertight 3D mesh in T-pose, correctly scaled and oriented
- Ready for dissection

### Failure Cases
| Issue | Resolution |
|---|---|
| Mesh not watertight | Auto-repair (trimesh.repair) |
| Mesh not in T-pose | Regenerate with T-pose pre-prompt |
| Mesh too thin in places | Flag to customer in dissection step |
| Mesh has internal geometry | Remove internal faces |
| Proportions don't match skeleton | Scale X/Y/Z independently to fit |

---

## Step 5: Dissect — Guided Body Zone Cutting

**Goal:** Customer walks through cutting the character into 5 body zones, confirming each cut.

This is the **interactive, customer-facing step**. The software proposes cuts; the customer adjusts and confirms.

### Process

#### 5a. Auto-propose cut planes

Software analyzes the mesh and proposes initial cut positions using defaults from INTERFACE_SPEC:

```python
cuts = {
    "head_torso": {"type": "horizontal", "z": 115, "range": (105, 130)},
    "torso_base": {"type": "horizontal", "z": 10, "range": (0, 20)},
    "left_arm":   {"type": "vertical",   "x": -28, "range": (-35, -24)},
    "right_arm":  {"type": "vertical",   "x": 28, "range": (24, 35)},
}
```

Smart defaults: if the mesh has a visible neck narrowing, snap head cut to narrowest point. If arms are clearly separated from torso, snap arm cuts to the gap.

#### 5b. Customer walks through each cut

For each cut, the UI shows:

1. **3D view** of the character with the cut plane highlighted
2. **Slider** to move the cut plane up/down (or left/right for arms)
3. **Preview** of the two resulting pieces (above/below the cut)
4. **Warnings** if the cut:
   - Intersects a servo position (blocked — can't cut there)
   - Creates a zone smaller than 15mm (warning)
   - Creates a zone that won't clear a joint (warning)
5. **Confirm** button to lock the cut and move to the next one

#### Cut sequence
1. Head / Torso (horizontal) — most intuitive, start here
2. Left arm (vertical)
3. Right arm (vertical)
4. Torso / Base (horizontal)

After all 4 cuts: customer sees the **exploded view** — all 6 pieces separated, colored by zone (torso = front + back clamshell). Confirm to proceed.

#### 5c. Validation

After all cuts are confirmed, validate:
- [ ] Every zone has minimum dimensions (15mm in any axis)
- [ ] No servo position falls inside a shell zone (servos stay in skeleton)
- [ ] Magnet positions are reachable (not cut through)
- [ ] Each zone can physically slide onto/off the skeleton (no undercuts that trap it)

### Output
- 5 separate mesh pieces (raw, not yet hollowed)
- Cut plane positions recorded for this character

---

## Step 6: Finalize — Hollow + Magnet Bosses

**Goal:** Turn each solid zone piece into a printable hollow shell with magnet attachment features.

### Process per Zone

#### 6a. Hollow the shell (Skeleton Subtraction Method)

1. **Build clearance volume** for this zone — the skeleton geometry (servos, brackets, column) expanded by 1.5mm clearance per side, plus joint rotation sweep volumes
2. **Apply draft taper** along the removal direction (1.5-2° angle so shell slides on/off easily)
3. **Boolean subtract** clearance volume from the solid zone piece → shell with exact skeleton-shaped cavity
4. **Torso special case:** Split into front/back clamshell halves along the XZ plane (Y=0), since the torso can't slide over shoulder brackets as one piece
5. **Validate wall thickness** — scan for any region thinner than 2mm after subtraction. Flag thin spots to customer or auto-thicken.

**Shell removal directions:**

| Zone | Removal | Draft Angle | Notes |
|---|---|---|---|
| Head | Lifts up (+Z) | 2° | Neck opening must clear magnet ring |
| Torso | Clamshell front/back | 1° | Each half pulls away along ±Y |
| Arms | Slide outward (±X) | 2° | Inboard face is open |
| Base | Lifts off (-Z) | 1.5° | Top face is open |

#### 6b. Select magnet positions

For each zone, run the magnet selection algorithm (defined in INTERFACE_SPEC):

1. Get all candidate magnet positions for this zone from skeleton spec
2. Check which ones the shell has enough wall thickness for (≥6mm at that point)
3. Score by distribution balance + edge distance
4. Select minimum required count (or more if shell geometry supports it)

#### 6c. Merge magnet bosses

For each selected magnet position:

1. Create a boss cylinder (⌀10mm × 4mm tall) on the shell's inner surface
2. Orient boss so pocket faces toward skeleton magnet
3. **Boolean union** boss with shell
4. **Cut** magnet pocket (⌀6.1mm × 3.1mm) into boss
5. Verify boss doesn't punch through shell outer surface

#### 6d. Joint clearance trimming

Check each joint's range of motion. If the shell would collide with an adjacent shell during movement:

1. Simulate the joint rotation at 5° increments through full ROM
2. Find any intersection between this shell and adjacent shells
3. **Trim** the interfering region with a swept boolean cut
4. Re-validate wall thickness after trimming

### Output per Zone
- Hollow shell mesh with magnet bosses
- Magnet position list (which skeleton magnets this shell uses)
- Validation report (wall thickness, clearance, magnet count)

---

## Step 7: Export — Print-Ready Files

**Goal:** Generate final STL files ready for 3D printing.

### Process

1. **Orient for printing** — lay each shell in optimal print orientation:
   - Head: upside down (opening up), minimizes supports
   - Torso: on its back or upright depending on geometry
   - Arms: on flat side
   - Base: upside down (opening up)

2. **Generate supports** (or mark support-free orientation)

3. **Export STL** per zone (6 files — torso is 2 pieces):
   ```
   character_shells/
   ├── head_shell.stl
   ├── torso_front_shell.stl
   ├── torso_back_shell.stl
   ├── left_arm_shell.stl
   ├── right_arm_shell.stl
   └── base_shell.stl
   ```

4. **Export assembly preview** — combined STL/3MF with all shells + skeleton for visual verification

### Quality Checks
- [ ] All meshes manifold (watertight)
- [ ] No degenerate triangles
- [ ] File size reasonable (< 50MB per piece)
- [ ] Fits printer bed (max 220×220×250mm — standard Ender 3)

---

## Step 8: Print + Ship

**Goal:** Physical shells arrive at customer's door.

### Fulfillment Options
| Option | Description |
|---|---|
| Partner print farm | Send STLs to print service → ship to customer |
| In-house printing | Print at HawaBot facility |
| Customer prints | Provide STL files for home printing (future) |

### Kit Contents
- 5 shell parts (labeled)
- Bag of 6×3mm magnets (count matches shell requirements)
- Instruction card (snap magnets into pockets, place shells on skeleton)
- QR code → setup guide in HawaBot app

---

## Pipeline Code Architecture

```
pipeline/
├── SKELETON_SPEC.md          # Skeleton frame design (fixed)
├── INTERFACE_SPEC.md         # Shell↔skeleton contract (fixed)
├── SHELL_PIPELINE_SPEC.md    # This document
│
├── skeleton.py               # Skeleton geometry + magnet positions
├── generate_skeleton_step.py # CadQuery STEP export for skeleton
│
├── dissect.py                # Step 5: Cut mesh into zones
├── hollow.py                 # Step 6a: Shell hollowing
├── magnets.py                # Step 6b-c: Magnet selection + boss merge
├── clearance.py              # Step 6d: Joint clearance trimming
├── validate.py               # Validation checks across all steps
├── export.py                 # Step 7: Print-ready STL generation
│
├── shell_pipeline.py         # Orchestrator: runs steps 4-7 end to end
└── skeleton_exports/         # Generated skeleton files
```

### Key Dependencies
- `trimesh` — mesh loading, manipulation, boolean ops
- `manifold3d` — robust boolean operations (subtract, union)
- `cadquery` — parametric CAD for skeleton STEP generation
- `numpy` — geometry math
- `Meshy API` (or equivalent) — 3D model generation (Step 4)

---

## Data Flow Summary

```
Photo/Text ──→ 2D Views ──→ 3D Mesh ──→ 5 Solid Zones ──→ 5 Hollow Shells ──→ 5 STL Files
                  │              │              │                  │
                  │         Scale + Orient   Cut planes      Magnet bosses
                  │         Repair mesh     (customer        (auto-selected)
                  │                          adjusts)       Joint trimming
                  │
            Skeleton silhouette
            overlay (fixed)
```

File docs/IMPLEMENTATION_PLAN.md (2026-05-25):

# HawaBot Implementation Plan

## Current State Assessment

### What Is Built (Working Code)

| Component | Path | Status | Notes |
|---|---|---|---|
| SDK core (`Robot` class) | `hawabot/robot.py` | Functional | Entry point, tier detection, body parts, teach-by-demo |
| Character profile system | `hawabot/character/` | Functional | YAML profiles, animations, expressions |
| Joint abstractions | `hawabot/joints/` | Functional | Head, Arms, Waist, Leg modules |
| Driver abstraction | `hawabot/drivers/` | Functional (mock + pico) | MockDriver complete; PicoDriver (legacy); ESP32Driver planned |
| Pico W firmware | `firmware/pico_w/main.py` | Implemented | Legacy prototype; ESP32-S3 firmware is production target |
| Simulation engine | `hawabot/sim/` | Functional | Joint state tracking, matplotlib visualizer |
| Tier config | `hawabot/config/tiers.py` | Functional | Spark/Pro definitions, joint specs (Core eliminated) |
| Shell pipeline | `pipeline/shell_pipeline.py` | Functional | Scale, subtract, trim, validate — tested on real meshes |
| Joint clearance cuts | `pipeline/joint_cuts.py` | Functional | Clearance volumes, section splitting |
| Skeleton builder | `pipeline/skeleton.py` | Functional | Parametric skeleton generation per tier |
| Web prototype | `web/app.py` | Functional | Flask + Three.js, Meshy API integration, pipeline integration |
| Curriculum structure | `missions/` | Scaffolded | 5-month directory structure, month_01 prompts started |
| AI tutor | `hawabot/tutor/` | Scaffolded | Module structure in place, prompts directory |
| Teach-by-demo | `hawabot/teach.py` | Functional | Record/playback with JSON serialization |

### What Remains

| Component | Priority | Effort | Dependency |
|---|---|---|---|
| ~~PicoDriver (Spark)~~ | ~~P0~~ | ~~Done~~ | ~~Implemented 2026-04-28 (legacy prototype)~~ |
| ESP32Driver (Spark/Pro) | P0 | 3-4 weeks | ESP32-S3-DevKitC-1 in hand (parts ordered) |
| AI tutor implementation | P0 | 2-3 weeks | Anthropic API key, prompt engineering |
| Curriculum content (25 missions) | P0 | 6-8 weeks | SDK stable, tutor working |
| Production web platform | P1 | 8-12 weeks | Design finalized, Stripe integration |
| Skeleton physical prototyping | P0 | 4-6 weeks | 3D printer, servo stock |
| Assembly instructions | P1 | 2 weeks | Physical prototype complete |
| COPPA compliance review | P0 | 2-4 weeks | Legal counsel |
| Payment + fulfillment system | P1 | 4-6 weeks | Web platform, Stripe |
| Custom PCB (ESP32-S3 + PCA9685) | P1 | 4-6 weeks | ESP32Driver validated on devkit |
| Pro tier skeleton + drivers | P2 | 6-8 weeks | Spark validated, XL330 + Dynamixel bus |
| Pi5Driver (Max, future) | P3 | 3-4 weeks | Max tier development begins |

---

## Phased Build Plan

### Phase 0: Foundation (Weeks 1-4) -- IN PROGRESS

**Goal:** Validate the full pipeline end-to-end with a physical Spark prototype.

| Task | Owner | Duration | Status |
|---|---|---|---|
| Order Spark hardware (5x SG90 + 2x MG90S + PCA9685, ESP32-S3-DevKitC-1, MAX98357A) | Hardware | Week 1 | **Done** — Phase 1 parts ordered ($56) |
| 3D print first skeleton from `pipeline/skeleton.py` output | Hardware | Week 1-2 | TODO |
| ~~Implement PicoDriver (serial protocol for PWM servos)~~ | ~~Firmware~~ | ~~Done~~ | **Complete** (legacy) — `hawabot/drivers/pico.py` + `firmware/pico_w/main.py` |
| Implement ESP32Driver (WiFi REST/WebSocket for PWM servos) | Firmware | Week 2-3 | TODO |
| Test SDK -> ESP32Driver -> physical servo movement (7 DOF) | Integration | Week 3 | TODO |
| Print first character shell using pipeline output | Pipeline | Week 2-3 | Pipeline proven on meshes |
| Validate shell fits skeleton, magnets hold, joints clear | Hardware | Week 3-4 | TODO |
| Film first "kid unboxes and builds" prototype session | Validation | Week 4 | TODO |

**Critical path:** Phase 1 prototype parts ordered ($56, no breadboard — direct solder). ESP32Driver must work by Week 3. First assembled robot by Week 4.

**Exit criteria:**
- [ ] Physical Spark robot assembled and working (7 DOF)
- [ ] SDK controls real servos via ESP32Driver over WiFi
- [ ] Character shell fits and sections snap together
- [ ] At least one complete teach/play cycle on real hardware

---

### Phase 1: Spark MVP (Weeks 5-12)

**Goal:** Shippable Spark product with curriculum, tutor, and purchase flow.

#### 1A: AI Tutor (Weeks 5-7)

| Task | Duration | Dependency |
|---|---|---|
| Implement safety layer (Claude Haiku pre-classifier) | 1 week | Anthropic API access |
| Implement tutor layer (Claude Sonnet, system prompt + context injection) | 1 week | Safety layer |
| Character-aware prompt templates (inject name, tier, current mission) | 3 days | Character profile system |
| Test with 5-10 representative student interactions | 1 week | Tutor working |
| COPPA compliance review with legal counsel | 2-4 weeks (parallel) | Tutor design finalized |

#### 1B: Curriculum Content (Weeks 5-10)

| Task | Duration | Dependency |
|---|---|---|
| Month 1 missions (5 missions): Joints, DOF, basic motion | 2 weeks | SDK stable |
| Month 2 missions (5 missions): Sensing, ultrasonic, reactions | 2 weeks | Month 1 complete |
| Tutor prompt files for each mission | 1 week per month | Missions written |
| Starter code templates for each mission | Parallel with missions | SDK API finalized |
| Mission validation logic (event log checks) | 1 week | Missions designed |
| Beta test with 3-5 kids (ages 12-15) | 2 weeks | Month 1-2 content ready |

#### 1C: Production Platform (Weeks 6-12)

| Task | Duration | Dependency |
|---|---|---|
| Design UI/UX for design platform (Figma) | 2 weeks | None |
| Next.js frontend: character design flow | 3 weeks | UI design |
| Three.js Fiber 3D viewer (interactive preview) | 2 weeks | Parallel with frontend |
| Stripe payment integration (one-time + subscription) | 1 week | Frontend |
| User accounts (Clerk/Auth0) | 1 week | Frontend |
| Meshy API production integration (rate limits, error handling, queue) | 1 week | API key + account |
| Order management + fulfillment queue | 2 weeks | Payment working |
| Deploy to Vercel + set up CI/CD | 1 week | All above |

#### 1D: Manufacturing Pipeline (Weeks 8-12)

| Task | Duration | Dependency |
|---|---|---|
| Source servos, sensors, ESP32-S3 in bulk (100-unit MOQ) | 2 weeks | Phase 0 validated |
| Design custom PCB (ESP32-S3 + PCA9685 + MAX98357A, ~60x40mm 2-layer) | 3 weeks | Schematic finalized |
| Establish 3D print workflow (in-house Bambu Lab or partner) | 2 weeks | Shell pipeline proven |
| Design packaging (box, foam inserts, instruction card) | 2 weeks | Parallel |
| Assembly documentation (photo + video) | 1 week | Physical prototype |
| Assemble 10 beta kits | 1 week | All components in hand |
| Ship beta kits to testers | Week 12 | Kits assembled |

**Phase 1 exit criteria:**
- [ ] 10 beta kits shipped and tested by real kids
- [ ] AI tutor functional with safety layer passing COPPA review
- [ ] Month 1-2 curriculum complete and tested
- [ ] Production web platform deployed with payment flow
- [ ] Manufacturing process documented and repeatable

---

### Phase 2: Spark Launch + Pro Development (Weeks 13-20)

**Goal:** Public Spark launch ($199). Begin Pro tier development.

#### 2A: Spark Public Launch (Weeks 13-15)

| Task | Duration | Dependency |
|---|---|---|
| Incorporate beta tester feedback | 1 week | Beta results |
| Fix critical bugs from beta | 1-2 weeks | Beta results |
| Launch landing page + purchase flow | 1 week | Platform ready |
| Launch marketing campaign (see GO_TO_MARKET.md) | Ongoing | Platform live |
| First 50 customer orders fulfilled | Weeks 14-15 | Launch |
| Customer support process established | Week 13 | Launch |

#### 2B: Pro Tier Development (Weeks 13-20)

| Task | Duration | Dependency |
|---|---|---|
| Order Pro hardware (~$322: 10x XL330, additional SG90s, IMU, FSRs, mic, camera, battery) | Week 13 | Budget approved |
| Design Pro skeleton (19 DOF, XL330 mounting at shoulders+legs, same 250mm frame) | 3 weeks | Servos in hand |
| Extend ESP32Driver for Dynamixel bus (XL330 smart servos) | 3 weeks | ESP32-S3 + XL330s |
| Implement compliance mode for teach-by-demo on real hardware | 2 weeks | Dynamixel driver working |
| Extend shell pipeline for Pro skeleton (legs + arms) | 1 week | Pro skeleton designed |
| Month 3 curriculum: Feedback loops, IMU balance, walking basics | 2 weeks | Pro hardware working |
| Voice AI integration (SPH0641LU4H-1 mic -> Claude -> MAX98357A speaker) | 2 weeks | ESP32Driver + mic |
| Pro beta test (5 users) | 2 weeks | All above |

**Phase 2 exit criteria:**
- [ ] 50+ Spark kits sold and delivered
- [ ] Customer feedback incorporated, NPS measured
- [ ] Pro tier prototype working end-to-end (19 DOF walking)
- [ ] Month 3 curriculum written and tested
- [ ] Manufacturing process handling 20+ kits/week

---

### Phase 3: Pro Launch + B2B (Weeks 21-30)

**Goal:** Pro tier public launch ($599 all-in / $399 upgrade). Begin B2B channel.

| Task | Duration |
|---|---|
| Pro public launch | Week 21 |
| Upgrade path tested (Spark customer -> Pro via $399 add-on, same character) | Week 21-22 |
| Camera + computer vision integration (OV2640) | Weeks 22-26 |
| FSR-based walking tuning and gait optimization | Weeks 22-26 |
| Month 4-5 curriculum (advanced motion, walking, vision) | Weeks 23-28 |
| B2B pilot outreach (3-5 schools/camps) | Weeks 21-24 |
| Teacher dashboard (class management, progress tracking) | Weeks 25-30 |
| Custom PCB production run (Spark + Pro, same board) | Weeks 24-28 |

---

### Phase 4: Full Platform (Weeks 31-40)

**Goal:** Spark + Pro live and scaling. B2B channel active. Max in concept. Fundraise.

| Task | Duration |
|---|---|
| All 25 missions complete and tested | Week 31-32 |
| B2B pricing and contracts finalized | Week 31-33 |
| First school deployments (10-30 kit orders) | Week 33-36 |
| Character marketplace v1 (community sharing) | Week 34-38 |
| Max tier concept design (400-500mm, Pi 5/CM5, on-board AI) | Week 34-38 |
| Fundraising materials prepared | Week 35-36 |
| Seed round conversations begin | Week 36+ |

---

## Dependency Graph

```
Phase 0: Physical Prototype (ESP32-S3 + 7 DOF)
    |
    +---> ESP32Driver works -------+
    |                              |
    +---> Shell fits skeleton -----+---> Phase 1: Spark MVP ($199)
                                   |
                      AI Tutor ----+
                      Curriculum --+
                      Web Platform +
                      Manufacturing+
                                   |
                                   +---> Phase 2: Spark Launch
                                   |         + Pro Dev (19 DOF, XL330)
                                   |
                                   +---> Phase 3: Pro Launch ($599)
                                   |         + B2B
                                   |
                                   +---> Phase 4: Full Platform
                                             Spark + Pro scaling
                                             Max concept (future)
```

**Single biggest risk:** Physical prototype (Phase 0). If the shell does not fit the skeleton reliably, everything downstream is delayed. Phase 1 prototype parts are ordered ($56). ESP32Driver (WiFi REST/WS) is the next firmware priority — PicoDriver is legacy. The remaining risk is mechanical (skeleton fit, magnet attachment, joint clearances).

---

## Milestones and Success Metrics

| Milestone | Target Date | Success Metric |
|---|---|---|
| First physical Spark robot assembled | Phase 0, Week 4 | Robot moves all 7 DOF via SDK over WiFi |
| AI tutor passes COPPA review | Phase 1, Week 8 | Legal sign-off |
| 10 beta kits shipped | Phase 1, Week 12 | Kids complete Month 1 missions |
| Spark public launch ($199) | Phase 2, Week 13 | Platform live, accepting orders |
| 50 Spark kits sold | Phase 2, Week 16 | Revenue: ~$10,000 |
| 200 Spark kits sold | Phase 2, Week 20 | Revenue: ~$40,000 |
| Pro tier launched ($599) | Phase 3, Week 21 | Pro kits shipping, $399 upgrade path live |
| First B2B sale | Phase 3, Week 24 | School/camp pilot signed |
| 500 total kits sold (Spark + Pro) | Phase 3, Week 28 | Validates product-market fit |
| Spark + Pro scaling, Max in concept | Phase 4, Week 31 | Two tiers live, Max design started |
| 1,000 total kits sold | Phase 4, Week 36 | Seed round ready |

---

## Resource Requirements

### Team (Minimum Viable)

| Role | Responsibility | Phase Needed |
|---|---|---|
| Founder/Engineer | SDK, pipeline, architecture, everything | Phase 0+ |
| Firmware Engineer (part-time/contract) | ESP32Driver (WiFi), custom PCB design, Dynamixel integration | Phase 0-2 |
| Curriculum Designer (part-time) | Mission content, pedagogy, beta testing | Phase 1+ |
| Frontend Developer (contract) | Next.js platform, Three.js viewer | Phase 1 |
| 3D Print Operator (part-time) | Shell printing, assembly, QA | Phase 1+ |

### Hardware Budget (Phase 0-1)

| Item | Quantity | Unit Cost | Total |
|---|---|---|---|
| ESP32-S3-DevKitC-1 | 10 | $8 | $80 |
| SG90 servos | 50 | $1.50 | $75 |
| MG90S servos | 20 | $3.50 | $70 |
| PCA9685 breakout boards | 10 | $3 | $30 |
| MAX98357A breakout boards | 10 | $3 | $30 |
| 8ohm speakers | 10 | $2 | $20 |
| PLA filament (5 rolls) | 5 | $20 | $100 |
| 3D printer (Bambu Lab A1 Mini) | 1 | $300 | $300 |
| Neodymium magnets (6x2mm, bulk) | 200 | $0.10 | $20 |
| PCB prototyping (custom, JLCPCB) | 1 run | $150 | $150 |
| 5V power supply | 5 | $8 | $40 |
| Misc (hookup wire, solder, connectors, tools) | - | - | $100 |
| **Total** | | | **~$1,015** |

> **Note:** Phase 1 prototype parts already ordered ($56): ESP32-S3-DevKitC-1, HiLetgo PCA9685, SG90s, MG90S, MAX98357A, speaker, hookup wire, solder, 5V PSU. No breadboard — direct solder.

### Software/Service Budget (Monthly)

| Service | Cost/Month | Notes |
|---|---|---|
| Anthropic API (Claude) | $50-200 | Scales with users; ~$0.15/student/month |
| Meshy API | $30-100 | ~$0.30/generation; batch pricing available |
| Vercel (hosting) | $20-50 | Pro plan for production |
| Domain + email | $15 | hawalabs.com |
| Stripe | 2.9% + $0.30/txn | Per transaction |
| **Total (pre-launch)** | **~$120/month** | |

---

## Technical Debt and Known Issues

| Issue | Severity | Plan |
|---|---|---|
| PicoDriver is legacy, ESP32Driver needed for production | High | Implement ESP32Driver (WiFi REST/WS) in Phase 0 |
| ~~Tier config still references Core tier~~ | ~~Medium~~ | ~~Done — Core removed from tiers.py (2026-05-12)~~ |
| Web prototype is Flask, not production-ready | Medium | Rewrite to Next.js in Phase 1C |
| No automated tests for shell pipeline | Medium | Add pytest suite in Phase 1 |
| MockDriver does not simulate servo latency | Low | Add configurable delay in Phase 1 |
| Curriculum validation is basic (event log only) | Low | Sufficient for V1; enhance in Phase 3 |
| No CI/CD pipeline | Medium | GitHub Actions in Phase 1 |
| Character animations are hardcoded per profile | Low | Animation editor tool in Phase 3 |
| Shell pipeline does not handle non-manifold input gracefully | Medium | Add mesh repair stage with manifold3d.repair in Phase 1 |

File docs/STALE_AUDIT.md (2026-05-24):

# Documentation Staleness Audit

_Last audit: 2026-05-24. All HIGH and MEDIUM items resolved._

All documentation now reflects the two-tier strategy:
- **Spark** ($199, 7 DOF, desk companion)
- **Pro** ($599, 19 DOF, walking humanoid, same 250mm skeleton)
- **Max** ($999+, future flagship, 400-500mm, on-board AI)

---

## Resolved (2026-05-24)

| File | What Was Fixed |
|---|---|
| `pipeline/COMPONENT_REFERENCE.md` | Removed all Core references, updated MCU to ESP32-S3, fixed servo counts (SG90×4/MG90S×3 Spark, SG90×8/XL330×11 Pro), removed waist roll/LEDs/ultrasonic, updated compute board sections |
| `pipeline/SOLIDWORKS_BUILD_GUIDE.md` | Replaced Pi 5 with ESP32-S3 PCB, removed waist roll, added shoulder roll, removed LEDs/ultrasonic, updated assembly tree, fixed joint positions |
| `hawabot/drivers/pi5.py` | Changed "Pro tier" → "Max tier", removed Core (11 DOF) references |
| `pipeline/INTERFACE_SPEC.md` | Updated Pico USB → ESP32-S3 USB-C in clearance specs and assembly sequence |
| `pipeline/SKELETON_SPEC.md` | Changed "Core Humanoid" variant → "Max Humanoid", "Spark/Core" → "Spark/Pro" |
| `docs/IMPLEMENTATION_PLAN.md` | Struck through resolved Core tier tech debt item |
| `docs/GO_TO_MARKET.md` | Updated partnership from "Pi Pico W / Pi 5" → "ESP32-S3 (Spark/Pro), Pi 5 (Max future)" |
| `docs/ARCHITECTURE.md` | Added ESP32Driver to driver instantiation list |

## Resolved (2026-05-12)

| File | What Was Fixed |
|---|---|
| `CLAUDE.md` | Created from scratch with full current state |
| `hawabot/config/tiers.py` | Two tiers (Spark+Pro+Max), correct DOF/servos/MCU/pricing, Core removed |
| `docs/ARCHITECTURE.md` | ESP32-S3, correct DOFs, ESP32Driver added, PicoDriver marked legacy, shoulder roll corrected to SG90 |
| `docs/STRATEGY.md` | $199/$599/$999+ pricing, two tiers, systems engineering positioning |
| `docs/PRICING.md` | Complete rewrite with current BOM, credits model, competitive analysis |
| `docs/IMPLEMENTATION_PLAN.md` | Full rewrite: ESP32-S3, two tiers, correct phases, updated hardware budget |
| `docs/GO_TO_MARKET.md` | Updated pricing ($199/$599), removed Core tier, $39/mo subscription, updated revenue targets |
| `docs/COMPETITIVE_ANALYSIS.md` | Updated pricing ($199/$599), added TonyPi competitor, two tiers, systems engineering positioning |
| `docs/TIER_COMPONENTS.md` | New — full component tables for Spark, Pro, Max with interfaces and intent |
| `hawabot/drivers/pi5.py` | Docstring updated — Max tier only |
| `pipeline/SKELETON_SPEC.md` | Staleness banner + redirect to PARAMETRIC_PIPELINE_PLAN.md |
| `solidworks_package/PARAMETRIC_PIPELINE_PLAN.md` | All Core→Pro, two-tier architecture, correct MCU table |
| `solidworks_package/SOLIDWORKS_CONTEXT.md` | New — cowork reference with full hardware context |
| `docs/PROTOTYPE_BOM_CHECKLIST.md` | Phase 1 ordered ($56), no breadboard (soldered), custom PCB reference |

## Still Pending (Low Priority)

| File | Issue | When to Fix |
|---|---|---|
| `pipeline/SHELL_PIPELINE_SPEC.md` | May reference old skeleton model | When pipeline code is modified |
| `pipeline/COMPONENT_REFERENCE.md` | Partially duplicated in solidworks_package/ | Consolidate when convenient |
| `firmware/pico_w/main.py` | Legacy — needs ESP32-S3 port | When starting firmware development |
| `hawabot/drivers/pico.py` | Legacy — needs ESP32Driver equivalent | When ESP32 firmware is ready |

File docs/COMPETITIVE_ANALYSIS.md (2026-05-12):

# HawaBot Competitive Analysis

## Executive Summary

The educational robotics market ($1.8-2.5B, 14-19% CAGR) is dominated by players that were designed for a pre-AI, pre-Python world. LEGO Mindstorms is dead. SPIKE Prime retires June 2026. No competitor combines real Python programming, AI-native curriculum, custom physical characters, and a progressive hardware path. HawaBot enters a market with massive demand and a widening supply gap.

---

## Competitive Landscape

### Tier 1: Direct Competitors (Educational Robotics Kits)

#### LEGO Education (SPIKE Prime / Mindstorms)

| Dimension | LEGO | HawaBot |
|---|---|---|
| **Status** | SPIKE Prime retiring June 2026; Mindstorms discontinued 2022 | Active development |
| **Price** | $396 (SPIKE Prime) | $199-599 |
| **Age Range** | 9-14 | 12-15 |
| **Programming** | Scratch-based (block coding), limited Python via extension | Native Python from day one |
| **AI Integration** | None | AI tutor (Claude), AI concepts in curriculum, AI-generated characters |
| **Customization** | Brick-built (standard LEGO) | Fully custom 3D-printed character shells |
| **Hardware Progression** | Single SKU, no upgrade path | 2 tiers + future flagship, same character shell |

**Key gap exploited:** LEGO is abandoning the advanced segment. Their block-based programming caps out at age 12-13. No AI. No Python. No path to real engineering.

#### VEX Robotics (VEX GO / IQ / V5)

| Dimension | VEX | HawaBot |
|---|-----|---|
| **Price** | $200-2,500+ | $199-599 |
| **Focus** | Competition robotics (VEX tournaments) | Creative expression + AI literacy |
| **Programming** | VEXcode (proprietary), block + text | Standard Python (transferable skill) |
| **AI Integration** | None | Core to platform |
| **Target** | School teams, competition-focused | Individual kids, self-paced learning |
| **Customization** | Modular metal/plastic construction | Custom AI-generated 3D character |
| **Emotional Connection** | Functional machines | Named character with personality |

**Key gap exploited:** VEX optimizes for competition, not learning. Proprietary language. No AI. No creative ownership. Expensive for individual families.

#### Hiwonder TonyPi (Closest Direct Competitor to Pro)

| Dimension | TonyPi | HawaBot Pro |
|---|---|---|
| **Price** | $570 | $599 |
| **DOF** | 18 | 19 |
| **Compute** | Raspberry Pi 5 | ESP32-S3 (AI offloaded to phone) |
| **Form Factor** | Walking humanoid | Walking humanoid |
| **Programming** | Python (ROS-style) | Python SDK |
| **AI Integration** | OpenCV vision, no AI tutor | AI tutor (Claude), AI curriculum, AI-generated characters |
| **Customization** | Fixed plastic shell | Custom 3D-printed character shells |
| **Curriculum** | Example scripts, no structured curriculum | 25-mission systems engineering curriculum |
| **Target** | Hobbyists, university students | Kids 12-15, structured learning |

**Key gap exploited:** TonyPi is the closest hardware competitor at a similar price and DOF count, but it ships as a generic robot with no curriculum, no AI tutoring, no character customization, and no structured learning path. It is a hobbyist kit, not an educational platform.

#### Makeblock (mBot / CyberPi / mBot Neo)

| Dimension | Makeblock | HawaBot |
|---|---|---|
| **Price** | $60-200 | $199-599 |
| **Form Factor** | Wheeled robot, sensor boards | Humanoid character (tabletop to bipedal) |
| **Programming** | mBlock (Scratch-based), Arduino C++ | Python SDK |
| **AI Integration** | Basic ML image recognition | AI tutor, AI concepts throughout curriculum |
| **Customization** | Snap-on accessories | Full custom character design |
| **Curriculum** | Lesson plans available | 25-mission structured curriculum with AI tutor |

**Key gap exploited:** mBot is a wheeled robot with limited expressiveness. No character system. No humanoid form. Block coding limits ceiling.

#### Sphero (BOLT / RVR)

| Dimension | Sphero | HawaBot |
|---|---|---|
| **Price** | $150-280 | $199-599 |
| **Form Factor** | Rolling ball / wheeled platform | Humanoid character |
| **Programming** | Sphero Edu (block + JS + Python-lite) | Full Python SDK |
| **AI Integration** | None | Core to platform |
| **Customization** | None (fixed form factor) | Full custom character |
| **Emotional Connection** | Limited (it is a ball) | Named character with expressions |

**Key gap exploited:** Sphero is fun but shallow. No construction. No progression. No AI. Limited programming depth.

### Tier 2: Adjacent Competitors (Maker/AI Platforms)

#### Arduino Education Kits

| Dimension | Arduino | HawaBot |
|---|---|---|
| **Price** | $30-200 | $199-599 |
| **Programming** | C/C++ (Arduino IDE) | Python |
| **Structure** | Unstructured; requires self-direction | 25-mission guided curriculum |
| **AI Integration** | None native | Core to platform |
| **Physical Form** | Breadboard + wires (no character) | Custom 3D-printed robot |
| **Target Age** | 14+ (effectively) | 12-15 |

**Key gap exploited:** Arduino is too unstructured for 12-year-olds. C++ is a barrier. No physical robot out of the box. No AI.

#### NVIDIA Jetson / Jetbot

| Dimension | NVIDIA Jetson | HawaBot |
|---|---|---|
| **Price** | $200-600+ | $199-599 |
| **Programming** | Python + JupyterLab | Python SDK |
| **AI Integration** | Strong (vision, inference) | AI tutor + curriculum |
| **Target** | College students, hobbyists | Kids 12-15 |
| **Curriculum** | University-level, self-guided | Age-appropriate, structured, Socratic |
| **Assembly** | Complex, requires expertise | Designed for kid assembly |
| **Character** | None | Custom character system |

**Key gap exploited:** Jetson is overkill for a 13-year-old. No curriculum. No emotional hook. Not designed for education.

#### Unitree / Boston Dynamics EDU

| Dimension | Research Robots | HawaBot |
|---|---|---|
| **Price** | $1,600-16,000+ | $199-599 |
| **Target** | Universities, research labs | K-12 (specifically 12-15) |

**Key gap exploited:** Wrong audience entirely. But these platforms demonstrate the aspirational endpoint that HawaBot's curriculum builds toward.

---

## Feature Comparison Matrix

| Feature | HawaBot | LEGO SPIKE | VEX IQ | Makeblock | Sphero | Arduino |
|---|---|---|---|---|---|---|
| **Python (real)** | Yes | Limited | No | No | Limited | No (C++) |
| **AI Tutor** | Yes | No | No | No | No | No |
| **AI in Curriculum** | Yes | No | No | Basic ML | No | No |
| **Custom Character** | Yes | No | No | No | No | No |
| **Humanoid Form** | Yes | Buildable | Buildable | No | No | No |
| **Teach-by-Demo** | Yes (Pro) | No | No | No | No | No |
| **Voice AI** | Yes (Pro) | No | No | No | No | No |
| **Computer Vision** | Yes (Pro) | No | Yes (V5) | Basic | No | Add-on |
| **Progressive HW** | 2 tiers + future flagship | 1 SKU | 3 lines | 2-3 lines | 2 lines | Open |
| **Structured Curriculum** | 25 missions | Yes | Yes (comp) | Some | Some | No |
| **Subscription Model** | Yes | No | No | No | No | No |
| **Entry Price** | $199 | $396 | $200 | $60 | $150 | $30 |
| **Age Range Sweet Spot** | 12-15 | 9-13 | 10-18 | 8-14 | 8-13 | 14+ |

---

## Gap Analysis: Where HawaBot Wins

### Gap 1: The Post-LEGO Void (Ages 12-15)

LEGO ages out at 13. Arduino is too hard at 12. VEX is competition-focused. There is a 3-year gap (12-15) where kids who loved LEGO robotics have nowhere to go. This is the fastest-growing STEM segment (9.96% CAGR) and the least served.

**HawaBot fills this gap** with age-appropriate hardware, real Python, structured curriculum, and an AI tutor that adapts to the student.

### Gap 2: AI Literacy Platform

28 states have issued AI education guidance. Boston mandates AI fluency for graduation starting September 2026. Yet no educational robotics platform teaches AI concepts. Schools are scrambling.

**HawaBot is AI-native.** AI concepts start in Month 1 ("What is a robot brain?") and culminate in Month 5 (reinforcement learning, LLM integration). The AI tutor itself demonstrates AI capability in every interaction.

### Gap 3: Emotional Ownership

Every competitor ships a generic robot. Same form factor for every kid. This is fine for a classroom but terrible for engagement at home.

**HawaBot's character system** creates genuine ownership. The kid designs their robot's appearance using AI or their own sketch. It arrives at their door with their character's face. Missions reference it by name. This drives:

- 3-5x higher engagement vs. generic robots (based on analogous data from character-driven games)
- Organic word-of-mouth (kids show off *their* unique robot)
- Natural upsell (new modules for a character they already love)

### Gap 4: Real Python, Not Block Code

Block-based programming (Scratch, VEXcode Blocks, mBlock) is appropriate for ages 8-11. By 12, motivated kids are ready for text-based code. By 14, block coding feels patronizing.

**HawaBot uses standard Python** — the same language used in AI, data science, web development, and every CS101 course. Code skills are directly transferable. The SDK is a real pip-installable package with type hints and proper documentation.

### Gap 5: Progressive Hardware Path

Most competitors offer a single product or disconnected product lines. Upgrading from LEGO to VEX means abandoning everything and starting over.

**HawaBot's tier system** (Spark -> Pro) keeps the same 250mm character shell. Spark ($199, 7 DOF desk companion) upgrades to Pro ($599 all-in, or $399 upgrade kit) which adds legs, arms, sensors, and walking. The kid's emotional investment compounds rather than resets. Max ($999+) is a future aspirational flagship — a larger 400-500mm robot with on-board AI for graduates who complete the full curriculum.

---

## Positioning Statement

**For parents of kids aged 12-15** who want their child to learn systems engineering, AI, and robotics, **HawaBot** is the **only educational robotics platform** that lets kids **design their own AI-powered robot character**, have it **physically built and shipped to them**, and then **operate and teach it using real Python and an AI tutor**. Unlike LEGO, VEX, or Makeblock, HawaBot combines **custom physical characters, native Python, AI-integrated systems engineering curriculum, and a progressive hardware path** (Spark -> Pro) — all starting at $199.

---

## Competitive Response Scenarios

### Scenario 1: LEGO launches AI robotics product

**Likelihood:** Medium (12-18 months)
**Impact:** High
**Our response:** LEGO will likely use block coding + simplified AI. We differentiate on real Python, custom characters, and depth of AI integration. LEGO's strength (brand) is also a constraint (they move slowly, target younger).

### Scenario 2: Makeblock or Sphero adds AI tutor

**Likelihood:** Medium (6-12 months)
**Impact:** Medium
**Our response:** An AI tutor bolted onto a wheeled robot is not the same as an AI-native platform. Our character system + humanoid form + progressive curriculum is the full stack, not just a chatbot layer.

### Scenario 3: New startup copies the character concept

**Likelihood:** Low-Medium (12+ months)
**Impact:** Medium
**Our response:** The shell pipeline is genuinely hard to build (computational geometry + 3D printing constraints + servo fitting). We have working code today. A new entrant needs 6-12 months to replicate, by which time we have community, curriculum, and brand. File provisional patent on shell pipeline process.

### Scenario 4: Schools standardize on a different platform

**Likelihood:** Medium
**Impact:** Medium (B2B channel only)
**Our response:** B2C first. Build demand from students, then sell into schools where kids already want HawaBot. Bottom-up adoption, not top-down sales.

---

## Summary: Why HawaBot Wins

1. **Right product** — custom character + real Python + AI tutor + progressive hardware
2. **Right time** — LEGO exiting, AI mandates arriving, Python dominant
3. **Right audience** — 12-15 age gap is underserved and growing fastest
4. **Right moat** — shell pipeline is technically hard; character attachment is emotionally sticky
5. **Right economics** — $0.60 shells, commodity servos, software-driven margins at scale

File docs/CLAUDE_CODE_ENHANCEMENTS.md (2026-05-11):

# Future .claude/ Enhancements

Recommendations based on the Claude Code Project Structure Reference guide, tailored to HawaBot's multi-domain workflow (hardware + firmware + pipeline + web + curriculum).

---

## Skills (Auto-activate on task match)

Skills are reusable Claude Code capabilities with instructions, scripts, and reference materials. Each lives in `.claude/skills/<name>/`.

### Recommended Skills

#### `pcb-review`
Auto-activates when working on custom PCB design or KiCad files.
```
.claude/skills/pcb-review/
├── SKILL.md          # Instructions: check pin conflicts, antenna keep-out, power rail separation
├── references/
│   └── esp32s3_pin_allocation.md  # From project_custom_pcb.md memory
└── assets/
    └── pcb_checklist.md           # DFM checklist for JLCPCB
```

#### `servo-engineering`
Auto-activates when discussing servo selection, joint design, or torque analysis.
```
.claude/skills/servo-engineering/
├── SKILL.md          # Instructions: check cantilever loads, verify pocket dimensions, reference servo survey
├── references/
│   └── servo_survey.md            # Full servo comparison table
│   └── pocket_dimensions.md       # Clearances per servo type
```

#### `solidworks-sync`
Auto-activates when preparing files for the SolidWorks machine.
```
.claude/skills/solidworks-sync/
├── SKILL.md          # Instructions: verify mate table, check for stale data, list STEP files needed
├── references/
│   └── v17_axis_architecture.md   # Plane/axis naming and architecture
```

#### `curriculum-design`
Auto-activates when writing mission content or lesson plans.
```
.claude/skills/curriculum-design/
├── SKILL.md          # Instructions: systems engineering focus, NOT coding focus, Socratic method
├── references/
│   └── curriculum_positioning.md  # From memory
│   └── learning_layers.md         # 7 system layers (mechanical → AI)
```

---

## Agents (Isolated parallel work)

Agents are subagent definitions for complex, multi-step tasks that benefit from isolation.

### Recommended Agents

#### `bom-optimizer`
Researches component pricing, checks availability, suggests alternatives.
```yaml
# .claude/agents/bom-optimizer.yml
name: BOM Optimizer
description: Research current pricing and availability for robot components
tools: [WebSearch, WebFetch, Read, Write]
instructions: |
  Search reliable suppliers (RobotShop, Adafruit, DigiKey, Mouser) for current
  pricing. Flag out-of-stock items. Suggest alternatives within spec. Never
  trust AliExpress pricing without verification. Report in table format.
```

#### `compliance-checker`
Reviews design decisions against FCC/CE/safety requirements.
```yaml
# .claude/agents/compliance-checker.yml
name: Compliance Checker
description: Check hardware design decisions against regulatory requirements
tools: [WebSearch, WebFetch, Read]
instructions: |
  Verify FCC modular certification status of RF modules. Check age-appropriate
  safety requirements (CPSIA, ASTM F963 for 12+ products). Flag any component
  that may need additional certification.
```

#### `doc-updater`
Systematically updates stale documentation to match current decisions.
```yaml
# .claude/agents/doc-updater.yml
name: Documentation Updater
description: Update stale docs to match CLAUDE.md and memory
tools: [Read, Edit, Write, Glob, Grep]
instructions: |
  Read CLAUDE.md for current decisions. Read the target file. Identify
  all discrepancies. Make minimal edits to bring the file current.
  Do not rewrite sections that are already correct.
```

---

## Hooks (Lifecycle event scripts)

Hooks run automatically on Claude Code events. These prevent common mistakes.

### Recommended Hooks

#### PreToolUse: Protect golden files
Block edits to validated SolidWorks files without explicit confirmation.
```json
{
  "hooks": {
    "PreToolUse": [{
      "matcher": "Edit|Write",
      "command": "check-golden-files.sh"
    }]
  }
}
```
`check-golden-files.sh` would warn if editing:
- `solidworks_package/hawabot_ssp_macro_v17.bas`
- `solidworks_package/hawabot_skeleton_sketch.SLDPRT`
- Any `.step` reference files

#### PostToolUse: Lint Python after edits
```json
{
  "hooks": {
    "PostToolUse": [{
      "matcher": "Edit|Write",
      "command": "python -m ruff check --fix"
    }]
  }
}
```

#### SessionEnd: Save conversation summary
Auto-save key decisions from each session to a log.
```json
{
  "hooks": {
    "SessionEnd": [{
      "command": "save-session-summary.sh"
    }]
  }
}
```

---

## Commands (Slash commands already created)

| Command | Purpose | Created |
|---|---|---|
| `/review-bom` | Generate full BOM table for all tiers | Yes |
| `/sync-solidworks` | Prepare SolidWorks package, check for drift | Yes |
| `/audit-stale` | Find all stale docs and code | Yes |
| `/update-tiers` | Update hawabot/config/tiers.py to match current decisions | Yes |

### Future Commands to Add

| Command | Purpose | When to Add |
|---|---|---|
| `/design-pcb` | Guide custom PCB schematic design in KiCad | When starting PCB design |
| `/test-firmware` | Flash and test ESP32-S3 firmware | When firmware is ready |
| `/generate-skeleton` | Run CadQuery pipeline for a character | When pipeline is automated |
| `/prep-release` | Checklist for preparing a tier release | Before first production run |
| `/cost-analysis` | Full cost analysis including shipping, labor, margin | Before pricing finalization |

---

## Implementation Priority

| Enhancement | Effort | Impact | When |
|---|---|---|---|
| **CLAUDE.md** | Done | High | Now |
| **Slash commands (4)** | Done | High | Now |
| **Stale audit** | Done | High | Now |
| Skills (pcb-review) | 30 min | Medium | When starting PCB design |
| Skills (servo-engineering) | 30 min | Medium | When revisiting servo selection |
| Skills (curriculum-design) | 30 min | Medium | When writing mission content |
| Agent (bom-optimizer) | 15 min | Medium | Before next sourcing round |
| Agent (compliance-checker) | 15 min | High | Before production |
| Hooks (golden file protection) | 15 min | Low | When multiple people edit |
| Hooks (lint) | 5 min | Low | When code quality matters |

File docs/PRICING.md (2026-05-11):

# HawaBot — Pricing & Business Logic

**Last updated:** 2026-05-03

---

## 1. Bill of Materials — Spark Kit (7 DOF, 250mm)

### Electronics & Servos

| Component | Qty | Unit Cost (bulk 50+) | Subtotal |
|---|---|---|---|
| ESP32-S3 custom PCB (assembled) | 1 | $10.00 | $10.00 |
| SG90 Micro Servo | 5 | $1.50 | $7.50 |
| MG90S Metal Gear Servo | 2 | $2.50 | $5.00 |
| Speaker (28mm) + MAX98357A (on PCB) | 1 | $2.00 | $2.00 |
| 6×3mm Neodymium Magnets (N52) | 20 | $0.10 | $2.00 |
| M2×5mm Self-Tapping Screws | 10 | $0.02 | $0.20 |
| Servo wire harness / JST connectors | 1 | $0.50 | $0.50 |
| USB-C cable | 1 | $1.00 | $1.00 |
| **Electronics subtotal** | | | **$28.20** |

Note: PCA9685 PWM driver, MAX98357A amp, and power regulation are integrated on the custom PCB (~55×35mm, 2-layer). Same PCB for Spark and Pro (Pro populates additional mic, IMU, camera connector).

### 3D Printed Frame

| Component | Weight | Material Cost | Print Time | Subtotal |
|---|---|---|---|---|
| Skeleton frame (PLA/PETG) | ~60g | $0.90 | ~3 hrs | $0.90 |
| **Frame subtotal** | | | | **$0.90** |

### Spark Kit Total

| | Self-printed | Outsourced print |
|---|---|---|
| Electronics + magnets | $28.20 | $28.20 |
| Frame print | $0.90 (material only) | $5.00 (JLC3DP/PCBWay) |
| Assembly labor | — | $5.00 (estimate) |
| **BOM total** | **$29.10** | **$38.20** |

---

## 2. Custom Character Shells — Per Order

### 3D Generation

| Step | Provider | Cost |
|---|---|---|
| 2D preview views (4 views) | Image gen API | ~$0.05 |
| 3D model generation | Meshy API | ~$0.20-0.30 |
| **Generation subtotal** | | **~$0.30** |

### Shell Printing (5 parts)

| Part | Estimated Weight | Material Cost | Print Time |
|---|---|---|---|
| Head shell | 8-12g | $0.12 | 25 min |
| Torso shell | 15-25g | $0.30 | 50 min |
| Left arm shell | 5-10g | $0.08 | 20 min |
| Right arm shell | 5-10g | $0.08 | 20 min |
| Base shell | 10-15g | $0.15 | 30 min |
| **Total** | **43-72g** | **$0.73** | **~2.5 hrs** |

| | Self-printed | Print farm |
|---|---|---|
| Material | $0.73 | — |
| Print service fee | — | $8-15 (5 parts) |
| Shell magnets (10-15 pcs) | $1.00-1.50 | $1.00-1.50 |
| **Shell subtotal** | **~$2.25** | **~$12.50** |

### Shipping (US Domestic)

| Method | Cost | Delivery |
|---|---|---|
| USPS First Class Package | $4.63-5.50 | 1-3 days |
| USPS Ground Advantage | $4.50-6.00 | 2-5 days |

---

## 3. Full Cost Stack — Per Customer Order

### Scenario A: Spark Kit (New Customer)

Skeleton kit + first character shell set, shipped.

| Line Item | Self-Print | Outsourced |
|---|---|---|
| Skeleton kit BOM | $29.10 | $38.20 |
| Character generation (3D API) | $0.30 | $0.30 |
| Shell printing (5 parts) | $2.25 | $12.50 |
| Packaging | $1.00 | $1.00 |
| Shipping | $5.00 | $5.00 |
| **Total COGS** | **$37.65** | **$57.00** |

### Scenario B: Pro Upgrade (Existing Spark Customer)

Full leg system + shoulder upgrades + sensors + battery, shipped.

| Line Item | Cost |
|---|---|
| 4× SG90 servos (elbows + hands) | $8.00 |
| 2× XL330 servos (shoulder upgrade) | $54.00 |
| 8× XL330 servos (legs) | $216.00 |
| FSRs (4×) | $8.00 |
| Battery + TP4056 | $12.00 |
| IMU + mic + camera | $8.00 |
| Leg frame + feet (3D printed) | $10.00 |
| Packaging + shipping | $10.00 |
| **Total COGS** | **~$326.00** |

Retail: **$399 upgrade** (from Spark to Pro).

### Scenario C: Additional Character (Existing Customer)

New shell set only, shipped.

| Line Item | Self-Print | Outsourced |
|---|---|---|
| Character generation | $0.30 | $0.30 |
| Shell printing (5 parts) | $2.25 | $12.50 |
| Shell magnets | $1.25 | $1.25 |
| Packaging | $0.50 | $0.50 |
| Shipping | $5.00 | $5.00 |
| **Total COGS** | **$9.30** | **$19.55** |

---

## 4. Pricing Strategy

### Tier Pricing

| Tier | All-In Price | Upgrade Price | BOM Cost | Margin |
|---|---|---|---|---|
| **Spark** (7 DOF, 250mm) | $199 | — | ~$57 (outsourced) | 71% |
| **Pro** (19 DOF) | $599 all-in | $399 (from Spark) | ~$326 (upgrade COGS) | 18% upgrade / 36% all-in |
| **Max** (future) | $999+ | TBD | TBD | TBD |

Pro upgrades Spark with XL330 serial bus servos for legs and shoulders, full sensor suite (IMU, mic, camera), battery system, and walking capability. Max is a future tier with advanced compute and on-board AI.

### Credits Model (Fortnite-Style Add-Ons)

Credits buy robot capabilities — not just tutor access. Kids spend credits to make their character DO things.

| Add-On Type | Price | Examples |
|---|---|---|
| Movement pack | $5-10 | Dance routine, martial arts moves, wave patterns |
| Voice type | $5 | New TTS personality for speaker output |
| Animation | $5-10 | Choreographed sequence, reaction animations |
| New character shell | $15-25 | Different character appearance (printed + shipped) |
| Shell STL download | $14.99 | Self-print option (~95% margin) |

**Credits power the robot, not just the tutor.** This is the Fortnite model: the base game (robot) is the platform, credits buy emotes (movement packs, voice types, animations, personality).

### Build-As-You-Go Subscription ($39/mo × 6)

Each month ships a portion of the Spark kit + curriculum:

| Month | What Ships | What They Learn |
|---|---|---|
| 1 | ESP32-S3 PCB + base frame + waist servo | Electronics, first servo, serial bus |
| 2 | Head pan + tilt servos + head frame | Sensor input, pan/tilt control |
| 3 | R shoulder pitch + roll + arm frame | Kinematics, joint coordination |
| 4 | L shoulder pitch + roll + arm frame | Symmetry, mirroring, calibration |
| 5 | Shell kit (magnetic snap-on pieces) + speaker | Character design, personality, voice |
| 6 | AI tutor unlock + credits + graduation | Full system integration, challenges |

$39/mo × 6 = $234 total (slight premium over $199 one-time, justified by curriculum pacing).

---

## 5. Unit Economics
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

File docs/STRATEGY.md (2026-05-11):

# HawaBot Strategic Plan

## Vision

Every kid should be able to bring their imagined robot to life — design it, build it, understand how it works, and teach it. HawaBot is the platform that makes that possible.

## Mission

Hawa Labs builds the world's first character-driven physical AI robotics platform for kids aged 12-15. We combine custom 3D-printed robot characters, an ESP32-S3-based control system, structured systems engineering curriculum, and an AI tutor to create the most engaging path from "I have an idea" to "I understand how this system works."
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

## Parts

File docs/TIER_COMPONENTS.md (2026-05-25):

# HawaBot — Tier Component Reference

_Last updated: 2026-05-12_

Three tiers. Spark and Pro share the same 250mm skeleton and custom PCB. Max is a separate, larger robot.

---

## Spark ($199 — 7 DOF Desk Companion, 250mm)

Upper-body humanoid on a flat base. Entry point for the curriculum.

| Component | Qty | Interface | Intent |
|---|---|---|---|
| ESP32-S3-WROOM-1-N16R8 | 1 | — | Main MCU: 16MB flash, 8MB PSRAM, WiFi, I2C, I2S, GPIO. FCC modular cert. |
| PCA9685 PWM driver | 1 | I2C (0x40) | 16-ch servo control over single I2C bus |
| SG90 micro servo | 5 | PCA9685 PWM | Head pan, head tilt, L/R shoulder roll, waist yaw |
| MG90S metal gear servo | 2 | PCA9685 PWM | L/R shoulder pitch (higher torque for arm lift) |
| MAX98357A I2S amp | 1 | I2S0 | Audio output — voice, sound effects, personality |
| Speaker (28mm, 3W, 4ohm) | 1 | MAX98357A | Physical audio output |
| USB-C power supply (5V 3A) | 1 | — | Wall power for servos + logic |
| Neodymium magnets (6x3mm N52) | ~20 | — | Snap-on shell attachment to skeleton |
| M2x5mm self-tapping screws | ~10 | — | Servo mounting to skeleton frame |
| WS2812B RGB status LED | 1 | GPIO48 (NEOPIXEL) | System status: boot, WiFi, OTA, errors |
| Custom PCB (~60x40mm, 2-layer) | 1 | — | Integrates ESP32-S3 + PCA9685 + MAX98357A + power reg |
| 3D printed skeleton (PLA/PETG) | 1 | — | Structural frame: head, torso, arms, base |
| 3D printed character shell (5 pcs) | 1 set | — | Cosmetic magnetic snap-on: head, torso, L arm, R arm, base |

**Servo allocation (7 joints):**

| PCA9685 Ch | Joint | Servo | Load |
|---|---|---|---|
| CH0 | head_pan | SG90 | Light (~5g head shell) |
| CH1 | head_tilt | SG90 | Light |
| CH2 | left_shoulder_pitch | MG90S | Medium (~15-20g arm) |
| CH3 | left_shoulder_roll | SG90 | Light |
| CH4 | right_shoulder_pitch | MG90S | Medium (~15-20g arm) |
| CH5 | right_shoulder_roll | SG90 | Light |
| CH6 | waist_yaw | SG90 | Light (upper body rotation on base) |

**What Spark does:** Head tracks, shoulders wave, waist turns, speaker talks. AI tutor runs on phone/tablet via WiFi. No cables to phone.

---

## Pro ($599 all-in / $399 upgrade — 19 DOF Walking Humanoid, 250mm)

Same skeleton as Spark. Adds legs, arms, full sensor suite, and battery. Walks untethered.

### Everything in Spark, plus:

| Component | Qty | Interface | Intent |
|---|---|---|---|
| XL330-M288-T servo | 10 | UART1 Dynamixel bus | Shoulders upgraded (2) + 8 leg joints. Feedback + compliance for walking. |
| SG90 micro servo | +4 | PCA9685 PWM | L/R elbow pitch, L/R hand pitch |
| SPH0641LU4H-1 PDM MEMS mic | 1 | PDM (CLK + DATA) | Audio input — voice commands, sound detection |
| MPU6050 IMU | 1 | I2C (0x68) | Tilt + acceleration sensing for balance during walking |
| FSR 402 | 4 | ADC (GPIO1, 2, 11, 12) | Foot ground-contact detection — required for gait control |
| 10K resistors (FSR dividers) | 4 | — | Voltage dividers for FSR analog reading |
| OV2640 camera | 1 | DVP | Vision — face tracking, object recognition |
| LiPo battery (3.7V 1S, 2000mAh) | 1 | — | Untethered operation (can't walk on a cable) |
| TP4056 charger module | 1 | USB-C | Battery charging |
| TPS61023 boost converter (3.7V → 5.1V) | 1 | — | Boost LiPo 3.7V → 5.1V for servos. OR-ing diodes merge USB and battery power. |
| SS34 Schottky OR-ing diodes | 2 | — | Power path selection: USB vs battery (whichever is higher) |
| XL330 idler frame kit (FPX330-H101) | 1 | — | Dual-shaft support for shoulder and leg joints |
| XL330 cables (3-pin, 100mm) | 10 | — | Daisy-chain Dynamixel bus wiring |
| 3D printed leg frame + feet | 1 | — | Leg structure with FSR mounting points |

**Servo allocation (19 joints):**

| Bus | Joint | Servo | Notes |
|---|---|---|---|
| PCA9685 CH0 | head_pan | SG90 | Same as Spark |
| PCA9685 CH1 | head_tilt | SG90 | Same as Spark |
| PCA9685 CH3 | left_shoulder_roll | SG90 | Same as Spark |
| PCA9685 CH5 | right_shoulder_roll | SG90 | Same as Spark |
| PCA9685 CH7 | left_elbow_pitch | SG90 | New — Pro only |
| PCA9685 CH8 | left_hand_pitch | SG90 | New — Pro only |
| PCA9685 CH9 | right_elbow_pitch | SG90 | New — Pro only |
| PCA9685 CH10 | right_hand_pitch | SG90 | New — Pro only |
| Dynamixel | left_shoulder_pitch | XL330 | Upgraded from MG90S |
| Dynamixel | right_shoulder_pitch | XL330 | Upgraded from MG90S |
| Dynamixel | left_hip_yaw | XL330 | New — Pro only |
| Dynamixel | left_hip_pitch | XL330 | New — Pro only |
| Dynamixel | left_knee_pitch | XL330 | New — Pro only |
| Dynamixel | left_ankle_pitch | XL330 | New — Pro only |
| Dynamixel | right_hip_yaw | XL330 | New — Pro only |
| Dynamixel | right_hip_pitch | XL330 | New — Pro only |
| Dynamixel | right_knee_pitch | XL330 | New — Pro only |
| Dynamixel | right_ankle_pitch | XL330 | New — Pro only |
| Dynamixel | waist_yaw | XL330 | Upgraded from SG90 |

**Pro servo summary:** 8x SG90 (PCA9685 PWM) + 10x XL330 (Dynamixel bus) + 1x waist XL330 = 19 DOF

**What Pro adds over Spark:** Walking gait, arms with elbows and hands, voice input (mic), balance sensing (IMU), ground contact detection (FSRs), vision (camera), untethered battery operation. Full systems engineering experience.

---

## Max ($999+ — 19+ DOF Autonomous Humanoid, 400-500mm, Future)

Separate, larger robot. Not upgrade-compatible with the 250mm Spark/Pro skeleton. Aspirational flagship for enthusiasts who completed the Spark → Pro curriculum. Low volume, high margin, marketing halo.

| Component | Qty | Interface | Intent |
|---|---|---|---|
| Raspberry Pi 5 / CM5 | 1 | — | On-board AI inference — fully autonomous, no phone needed |
| XL330-M288-T servo | 19+ | Dynamixel bus | All joints on serial bus — position feedback + compliance on every joint |
| XL430-W250 servo | 2-4 | Dynamixel bus | High-torque joints (hips, shoulders) — 16 kg-cm for larger frame |
| MAX98357A I2S amp | 1 | I2S | Audio output |
| Speaker | 1 | MAX98357A | Voice, sound effects |
| MEMS mic (array) | 2-4 | I2S | Directional audio input — sound localization |
| IMU (ICM-42688-P or MPU6050) | 1 | I2C | Balance + orientation sensing |
| FSR 402 | 4+ | ADC | Foot contact detection for advanced gait |
| Camera (wide-angle) | 1 | CSI / USB | Vision — face tracking, object recognition, navigation |
| LIDAR (TFmini-S or similar) | 1 | UART / I2C | Obstacle detection + mapping |
| Ultrasonic sensor | 1-2 | GPIO | Close-range obstacle avoidance |
| LiPo battery (11.1V 3S, 2000mAh+) | 1 | — | Extended untethered operation |
| BMS + charging circuit | 1 | USB-C | Battery management + safe charging |
| Buck converters (12V→5V, 12V→3.3V) | 2 | — | Regulated power rails for servos + logic |
| Custom PCB (larger, 4-layer) | 1 | — | Integrates Pi CM5 + Dynamixel hub + power management + sensors |
| 3D printed skeleton (PETG/Nylon) | 1 | — | Larger structural frame — stiffer material for heavier loads |
| 3D printed character shell | 1 set | — | Magnetic snap-on cosmetic parts (larger) |

**What Max does differently:**
- **On-board AI** — runs inference locally on Pi 5/CM5, no phone required
- **Fully autonomous** — navigates, avoids obstacles, interacts without supervision
- **All-Dynamixel** — every joint has position feedback and compliance control
- **XL430 at high-load joints** — 16 kg-cm torque handles the heavier 400-500mm frame
- **Advanced sensing** — LIDAR + ultrasonic for spatial awareness, mic array for sound localization
- **Larger battery** — 3S LiPo for extended runtime with higher compute + servo draw

---

## Tier Comparison

| | Spark | Pro | Max |
|---|---|---|---|
| **Price** | $199 | $599 ($399 upgrade) | $999+ |
| **Size** | 250mm | 250mm | 400-500mm |
| **DOF** | 7 | 19 | 19+ |
| **Compute** | ESP32-S3 | ESP32-S3 | Pi 5 / CM5 |
| **AI brain** | Phone via WiFi | Phone via WiFi | On-board (autonomous) |
| **Servo types** | SG90 + MG90S | SG90 + XL330 | XL330 + XL430 |
| **Servo buses** | PCA9685 only | PCA9685 + Dynamixel | Dynamixel only |
| **Audio** | Speaker out | Speaker + mic | Speaker + mic array |
| **Sensors** | None | IMU, 4x FSR, camera | IMU, FSR, camera, LIDAR, ultrasonic |
| **Power** | USB-C wall | Battery (3.7V 1S + boost) | Battery (11.1V 3S) |
| **Locomotion** | Stationary (base) | Walking biped | Advanced gait |
| **Legs** | No | Yes | Yes |
| **Arms** | Shoulder only | + elbows + hands | Full articulation |
| **PCB** | Custom 2-layer (shared) | Custom 2-layer (shared) | Custom 4-layer (separate) |
| **Skeleton** | 250mm (shared) | 250mm (shared) | 400-500mm (separate) |
| **Upgrade path** | → Pro ($399) | → Max (separate purchase) | — |
| **Target** | Kids + parents, entry | Serious learners | Enthusiasts, graduates |
| **Volume** | High | Medium | Low (aspirational) |
| **BOM** | ~$57 | ~$383 | ~$500+ |
| **Margin** | ~71% | ~36% | TBD |

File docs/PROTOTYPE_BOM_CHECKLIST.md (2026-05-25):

# HawaBot Prototype BOM Checklist

_Last updated: 2026-05-24_

Build Spark first, validate, then expand to Pro with Dynamixel legs.

---

## Phase 1: Spark Prototype (7 DOF + Speaker)

Build and validate the Spark experience: servos, speaker, WiFi API.

### Already Have
- [x] ESP32-S3-DevKitC-1 dev board (check module variant — need N16R8)

### Purchased

| Item | Qty | Source | Price | Status |
|---|---|---|---|---|
| ESP32-S3-DevKitC-1-N16R8 dev board | 1 | Amazon (YEJMKJ B0CDRM6BGQ) | $12 | [ ] To Order |
| HiLetgo PCA9685 16-ch PWM breakout (2-pack) | 2 | Amazon (B07BRS249H) | $14 | [x] Ordered |
| SG90 micro servos | 5 | Amazon | $10 | [x] Ordered |
| MG90S metal gear servos | 2 | Amazon | $8 | [x] Ordered |
| MAX98357A I2S amp breakout | 1 | Adafruit (#3006) | $6 | [x] Ordered |
| Speaker (3W, 4ohm, 28mm) | 1 | Adafruit / Amazon | $2 | [x] Ordered |
| Hookup wire (22 AWG, solid core) | 1 spool | Amazon | $3 | [x] Ordered |
| Solder + flux | 1 | Amazon | $3 | [x] Ordered |
| 5V 3A USB-C power supply | 1 | Amazon | $10 | [x] Ordered |

Servo allocation:
- SG90 × 5: head pan, head tilt, L shoulder roll, R shoulder roll, waist yaw
- MG90S × 2: L shoulder pitch, R shoulder pitch
- PCA9685: 1 for use, 1 spare

### Phase 1 Total: ~$68

### What Phase 1 Validates

- [ ] ESP32-S3 → I2C → PCA9685 → 7 servos moving
- [ ] I2S audio out (speaker playback via MAX98357A)
- [ ] WiFi REST/WebSocket API (phone ↔ robot)
- [ ] OTA firmware updates
- [ ] Full Spark experience: head tracks, shoulders wave, waist turns, speaker talks

### Wiring (Phase 1)

```
ESP32-S3-DevKitC-1
  │
  ├─ I2C (GPIO8 SDA, GPIO9 SCL)
  │    └─ PCA9685 (addr 0x40) ──► 7 servo PWM channels
  │         ├─ CH0: head_pan (SG90)
  │         ├─ CH1: head_tilt (SG90)
  │         ├─ CH2: left_shoulder_pitch (MG90S)
  │         ├─ CH3: left_shoulder_roll (SG90)
  │         ├─ CH4: right_shoulder_pitch (MG90S)
  │         ├─ CH5: right_shoulder_roll (SG90)
  │         └─ CH6: waist_yaw (SG90)
  │
  ├─ I2S0 (GPIO4 BCLK, GPIO5 LRCLK, GPIO6 DOUT)
  │    └─ MAX98357A ──► Speaker (28mm, 3W, 4ohm)
  │
  └─ WiFi ──► Phone/tablet app

Power:
  5V 3A USB-C supply ──► PCA9685 V+ screw terminal (servo power)
  Dev board USB ──► ESP32-S3 logic power (separate from servo power)
```

---

## Phase 2: Pro Expansion (Add Legs + Arms + Sensors — 19 DOF)

Once Spark firmware and control are validated, add Dynamixel legs, arm servos, sensors, mic, and battery for walking.

### To Purchase

#### Dynamixel Servos + Wiring

| Item | Qty | Source | Est. Price | Status |
|---|---|---|---|---|
| XL330-M288-T servos | 8 | Robotis | $216 | [ ] |
| XL330 cable (3-pin, 100mm) | 10 | Robotis | $10 | [ ] |
| U2D2 (USB-Dynamixel adapter) | 1 | Robotis | $30 | [ ] |
| XL330 power board / 5V hub | 1 | Robotis | $10 | [ ] |
| FPX330-H101 idler frame kit (4-pack) | 1 | Robotis | $11 | [ ] |

Servo allocation (8x XL330):
- L/R hip yaw (2), L/R hip pitch (2), L/R knee pitch (2), L/R ankle pitch (2)

Note: Shoulders stay MG90S. Upgrade to XL330 later only if cantilever proves problematic under full arm load.

#### Additional Arm Servos

| Item | Qty | Source | Est. Price | Status |
|---|---|---|---|---|
| SG90 micro servos (elbows + hands) | 4 | Amazon | $8 | [ ] |

Servo allocation: L/R elbow pitch (2x SG90), L/R hand pitch (2x SG90)

#### Sensors

| Item | Qty | Source | Est. Price | Status |
|---|---|---|---|---|
| GY-521 (MPU6050 IMU breakout) | 1 | Amazon | $3 | [ ] |
| FSR 402 (force sensitive resistors) | 4 | Adafruit (#166) / Amazon | $8 | [ ] |
| 10K resistors (for FSR voltage dividers) | 4 | Amazon (assortment) | $1 | [ ] |
| SPH0641LU4H-1 PDM MEMS mic breakout | 1 | LCSC (C2879853) | $2 | [ ] |
| OV2640 camera module (DVP) | 1 | Amazon / AliExpress | $5 | [ ] |

#### Power (Walking Needs Battery)

| Item | Qty | Source | Est. Price | Status |
|---|---|---|---|---|
| LiPo battery (3.7V 1S, 2000mAh) | 1 | Amazon | $12 | [ ] |
| TP4056 charger module | 1 | Amazon | $2 | [ ] |
| TPS61023 boost module (3.7V → 5.1V) | 1 | Amazon | $3 | [ ] |
| SS34 Schottky diodes (OR-ing) | 2 | Amazon | $1 | [ ] |

### Phase 2 Total: ~$322

### What Phase 2 Validates

- [ ] Dynamixel bus control from ESP32-S3 UART1
- [ ] Mixed bus: PCA9685 (SG90/MG90S) + Dynamixel (XL330) simultaneously
- [ ] PDM audio in (mic capture + WiFi stream to phone)
- [ ] I2C IMU reading (tilt/acceleration)
- [ ] FSR analog reading (foot contact detection)
- [ ] DVP camera streaming (if applicable)
- [ ] Basic walking gait (pre-programmed)
- [ ] IMU + FSR assisted balance
- [ ] Battery operation (untethered walking)
- [ ] Full Pro experience: walks, talks, gestures, senses

### Wiring (Phase 2 additions)

```
ESP32-S3-DevKitC-1 (added to Phase 1 wiring)
  │
  ├─ I2C (shared bus, same GPIO8/9)
  │    └─ MPU6050 (addr 0x68) ──► IMU
  │
  ├─ PDM (GPIO15 CLK, GPIO7 DATA)
  │    └─ SPH0641LU4H-1 ──► Mic
  │
  ├─ ADC (GPIO1, GPIO2, GPIO11, GPIO12)
  │    └─ 4x FSR 402 (via 10K voltage dividers) ──► Foot contact
  │
  ├─ DVP (GPIO10-14, GPIO38-40) — if camera used
  │    └─ OV2640 ──► Camera
  │
  ├─ PCA9685 CH7-CH10 ──► 4x SG90 (elbows + hands)
  │
  └─ UART1 (GPIO17 TX, GPIO18 RX)
       └─ Dynamixel half-duplex bus ──► 8x XL330 (daisy-chained)

Power (Phase 2):
  LiPo 3.7V ──► TPS61023 boost (→ 5.1V) ──┐
  USB 5V ──► SS34 Schottky diode ──────────┤ OR-ing junction
  Boost out ──► SS34 Schottky diode ───────┘──► PCA9685 V+ (servos)
                                              ──► XL330 power hub
                                              ──► ESP32-S3 (via 5V pin)
```

---

## Grand Total

| Phase | Cost | Status |
|---|---|---|
| ESP32-S3-DevKitC-1 (original) | (already had) | [x] |
| ESP32-S3-DevKitC-1-N16R8 | $12 | [ ] To Order |
| **Phase 1: Spark** | **$68** | **Partially ordered** |
| **Phase 2: Pro expansion** | **$322** | [ ] After Spark validated |
| **Combined** | **$390** | |

---

## Custom PCB Reference (Future — After Soldered Prototype Validated)

Once Phase 1 is working with the soldered prototype, design a custom PCB (~55×35mm, 2-layer) in KiCad that consolidates everything onto one board. This replaces the soldered breakout boards for production.

### PCB Component Mapping (Breakout → IC)

| Breadboard Breakout | Production PCB Equivalent | Package | I/F |
|---|---|---|---|
| ESP32-S3-DevKitC-1 | ESP32-S3-WROOM-1-N16R8 module | Castellated SMD | — |
| HiLetgo PCA9685 board | PCA9685PW IC (TSSOP-28) + 25MHz crystal | SMD | I2C |
| MAX98357A breakout | MAX98357AETE+T IC (TQFN-16) | SMD | I2S |
| SPH0641LU4H-1 mic (Phase 2) | SPH0641LU4H-1 IC (LGA 3.5×2.65mm, LCSC C2879853) | SMD | PDM |
| GY-521 IMU breakout (Phase 2) | MPU-6050 IC (QFN-24) or ICM-42688-P | SMD | I2C |
| FSR voltage dividers (Phase 2) | 4x 10K resistors + ADC input traces | 0402/0603 | Analog |
| 5V USB-C power supply | USB-C connector + AP2112K-3.3 LDO | SMD | — |
| TPS61023 boost module (Phase 2) | TPS61023DRLR (SOT-5X3) + inductor + caps | SMD | — |
| SS34 Schottky diodes (Phase 2) | SS34 (SMA) × 2 — OR-ing USB vs battery | SMD | — |
| — | WS2812B RGB status LED (2020 package) | SMD | GPIO48 |
| Soldered hookup wire | PCB traces + JST-SH servo headers | — | — |

### PCB Features

| Feature | Spark (populated) | Pro (additionally populated) |
|---|---|---|
| ESP32-S3-WROOM-1-N16R8 module | Yes | Yes |
| PCA9685 PWM driver + 25MHz xtal | Yes | Yes |
| MAX98357A I2S amp | Yes | Yes |
| 9× 3-pin servo JST headers | 7 used | All 11 used |
| USB-C power + programming | Yes | Yes |
| 3.3V LDO (AP2112K-3.3) | Yes | Yes |
| 5V servo power rail + bulk caps | Yes | Yes |
| WS2812B RGB status LED | Yes | Yes |
| Boot + Reset buttons | Yes | Yes |
| SPH0641LU4H-1 PDM MEMS mic | **DNP** | Yes |
| MPU6050 IMU | **DNP** | Yes |
| 4× FSR analog inputs + dividers | **DNP** | Yes |
| OV2640 camera FPC connector | **DNP** | Yes |
| UART1 Dynamixel bus header | **DNP** | Yes |
| Battery connector (JST-PH 2-pin) | **DNP** | Yes |
| TP4056 charging circuit | **DNP** | Yes |
| TPS61023 boost converter (3.7V → 5.1V) | **DNP** | Yes |
| SS34 Schottky OR-ing diodes (×2) | **DNP** | Yes |

DNP = Do Not Populate (pads on PCB but no component soldered — saves cost for Spark, populated for Pro)

### PCB Design Notes

- **2-layer sufficient** — no impedance matching needed
- **Antenna keep-out:** No copper/ground pour within 15mm of ESP32-S3 antenna end
- **PCA9685:** Needs 25MHz crystal + 2× 22pF load caps + 10µF decoupling
- **MAX98357A:** Needs ferrite bead on PVDD + 10µF decoupling + gain select resistor
- **USB-C:** CC1/CC2 need 5.1K pull-down resistors for 5V power delivery
- **Servo power rail:** Separate from 3.3V logic. Common GND. Bulk cap (470µF) near PCA9685.
- **Design tool:** KiCad → fabricate at JLCPCB with SMT assembly
- **Estimated size:** ~60 × 40 × 8mm (fits in 250mm robot torso cavity)
- **Estimated cost:** ~$2-3/board + ~$15 assembly (prototype qty at JLCPCB)

### PCB Pin Allocation (Matching Breadboard Prototype)

| ESP32-S3 GPIO | Function | Phase |
|---|---|---|
| GPIO8 | I2C SDA (PCA9685 + MPU6050) | 1 |
| GPIO9 | I2C SCL (PCA9685 + MPU6050) | 1 |
| GPIO4 | I2S0 BCLK (MAX98357A) | 1 |
| GPIO5 | I2S0 LRCLK (MAX98357A) | 1 |
| GPIO6 | I2S0 DOUT (MAX98357A) | 1 |
| GPIO15 | PDM CLK (SPH0641LU4H-1) | 2 |
| GPIO7 | PDM DATA (SPH0641LU4H-1) | 2 |
| GPIO17 | UART1 TX (Dynamixel bus) | 2 |
| GPIO18 | UART1 RX (Dynamixel bus) | 2 |
| GPIO1 | ADC — FSR left front | 2 |
| GPIO2 | ADC — FSR left rear | 2 |
| GPIO11 | ADC — FSR right front | 2 |
| GPIO12 | ADC — FSR right rear | 2 |
| GPIO43 | UART0 TX (USB debug) | 1 |
| GPIO44 | UART0 RX (USB debug) | 1 |
| GPIO48 | Status LED (on-board RGB) | 1 |

**Avoid:** GPIO0, 45, 46 (strapping pins). GPIO19, 20 (USB OTG). GPIO35-37 (reserved on N8R8).

When your soldered prototype works, these exact pin assignments transfer to the KiCad schematic — no firmware changes needed.

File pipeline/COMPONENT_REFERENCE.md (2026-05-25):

# HawaBot — Component Reference & Placement Guide

Every component in the Pro skeleton with exact dimensions, mounting specifications, pocket/clearance requirements, and CAD file download links.

**Design for Pro (250mm), strip down for Spark.**

---

## Quick Reference — What Goes Where

```
HEAD:
├── SG90 × 2 (pan + tilt)                           All tiers
├── SPH0641LU4H-1 PDM mic (face area)              Pro only
└── OV2640 camera (face area)                       Pro only

TORSO:
├── MG90S × 2 (shoulder pitch, Spark)              Spark only
│   └── upgraded to XL330 × 2 (shoulder pitch, Pro)  Pro only
├── SG90 × 2 (shoulder roll)                        All tiers
├── SG90 × 2 (elbows)                               Pro only
├── SG90 × 2 (hands/grippers)                       Pro only
├── MG90S × 1 (waist yaw, Spark)                   Spark only
│   └── upgraded to XL330 × 1 (waist yaw, Pro)      Pro only
├── Speaker ⌀28mm (chest front)                     All tiers
├── MAX98357A amp board (behind speaker)             All tiers
└── MPU6050 IMU (torso center)                       Pro only

BASE PLATE / HIP:
├── ESP32-S3 custom PCB (~55×35mm)                  All tiers
├── PCA9685 (on custom PCB)                          All tiers
├── TP4056 USB-C charging board                      Pro only
├── LiPo battery 3.7V 1000mAh                       Pro only
├── USB-C breakout (power input)                     All tiers
└── Power switch                                     All tiers

LEGS (Pro only):
├── XL330 × 2 (hip yaw)
├── XL330 × 2 (hip pitch)
├── XL330 × 2 (knee)
├── XL330 × 2 (ankle)
└── Foot plates with rubber pads + FSRs
```

---

## 1. Servos

### 1.1 SG90 Micro Servo (×4 in Spark, ×8 in Pro)

**Used for:** Head pan, head tilt, L/R shoulder roll (all tiers), L/R elbow, L/R hand grip (Pro only)

| Spec | Value |
|---|---|
| Body L × W × H | 22.7 × 12.2 × 22.7 mm (body only) |
| Overall H (with shaft) | 32.3 mm |
| Tab-to-tab length | 32.3 mm |
| Tab thickness | 2.8 mm |
| Tab underside from bottom | 17.0 mm |
| Mounting holes | 2 per tab, ⌀2.0 mm, inset 2.0 mm from tab edge |
| Shaft center from front | 6.2 mm |
| Spline OD | 4.8 mm |
| Turret ⌀ | 11.8 mm |
| Turret height above body | 5.96 mm |
| Weight | 9 g |
| Torque | 1.8 kg·cm at 4.8V |
| Wire length | ~150 mm, 3-pin (signal, VCC, GND) |
| **Pocket size (with clearance)** | **23.3 × 12.8 × 23.3 mm** (body + 0.3mm/side) |
| **Tab slot size** | **32.9 × 12.8 × 3.4 mm** |
| **Turret clearance** | **⌀12.4 mm × 6.6 mm above body** |

**CAD file:** [GrabCAD — SG90](https://grabcad.com/library/sg90-micro-servo-9g-tower-pro-1) (STEP, free account)

**Clearances:**
- 0.3 mm per side around body (press fit, holds by tabs)
- Tab ledge: horizontal shelf at 17mm from bottom, servo rests on it
- Turret + horn: needs ⌀25mm × 10mm open space above body for horn rotation
- Cable exit: 4 × 6mm slot in pocket wall

---

### 1.2 MG90S Metal Gear Servo (×3 in Spark, ×0 in Pro)

**Used for:** L/R shoulder pitch + waist yaw (Spark only — Pro upgrades all three to XL330)

| Spec | Value |
|---|---|
| Body L × W × H | 22.8 × 12.4 × 22.5 mm |
| Overall H (with shaft) | 32.5 mm |
| Tab-to-tab length | 32.1 mm |
| Tab thickness | 2.8 mm |
| Tab underside from bottom | 18.5 mm |
| Mounting holes | 2 per tab, ⌀2.0 mm |
| Spline OD | 4.8 mm |
| Weight | 13.4 g |
| Torque | 2.2 kg·cm at 4.8V |
| **Pocket size (with clearance)** | **23.4 × 13.0 × 23.1 mm** |
| **Tab slot size** | **32.7 × 13.0 × 3.4 mm** |

**CAD file:** [GrabCAD — MG90S](https://grabcad.com/library/mg90s-servo-high-detail-1) (STEP, free account)

**Clearances:** Same as SG90 — 0.3mm/side, tab mounting, horn clearance.

---

### 1.3 Dynamixel XL330-M288-T (×11 in Pro)

**Used for:** L/R shoulder pitch (2), waist yaw (1), L/R hip yaw (2), L/R hip pitch (2), L/R knee (2), L/R ankle (2)

| Spec | Value |
|---|---|
| Body W × H × D | 20.0 × 34.0 × 26.0 mm |
| Weight | 18 g |
| Stall torque (5V) | 0.52 N·m (5.3 kg·cm) |
| Stall torque (6V) | 0.60 N·m (6.1 kg·cm) |
| Voltage range | 3.7–6.0 V (recommended 5.0V) |
| Protocol | TTL half-duplex serial, 9600–4Mbps |
| Connector | JST 3-pin (daisy-chain: 2 ports per servo) |
| Resolution | 4096 steps/rev (0.088°) |
| Gear ratio | 288.4:1 |
| Mounting | 4× M2 holes on bottom face, 8mm × 16mm pattern |
| Horn | Cross-type, 4-arm, spline: 20-tooth |
| Horn screws | M2×4 (center) |
| **Pocket size (with clearance)** | **21.0 × 35.0 × 27.0 mm** (0.5mm/side) |
| **Horn clearance above body** | **⌀30 mm × 8 mm** |

**CAD file:** [GrabCAD — XL330-288-T](https://grabcad.com/library/xl330-288-t-1) (STEP, free account)
**Datasheet:** [ROBOTIS e-Manual](https://emanual.robotis.com/docs/en/dxl/x/xl330-m288/)

**Clearances:**
- 0.5 mm per side (tighter tolerance than hobby servos — precision housing)
- Daisy-chain cable clearance: 8mm channel from servo to servo
- Horn rotation: ⌀30mm swept clear above mounting face
- M2 screw bosses: ⌀4mm posts at each mounting hole position

**Wiring note:** XL330 uses daisy-chain — each servo has 2 JST ports. Wire goes: ESP32 UART → first hip servo → knee → ankle. Only ONE data wire needed per leg (plus VCC + GND). Shoulder and waist XL330s can share a separate daisy-chain.

---

### 1.4 STS3215 Serial Bus Servo (reference only — not used in any current tier)

> **Not used in Spark, Pro, or Max.** Retained for reference/comparison only.

**Cheaper alternative for legs ($8-12 vs $24 per servo)**

| Spec | Value |
|---|---|
| Body L × W × H | 45.2 × 24.7 × 35.0 mm |
| Weight | 55 g |
| Stall torque (7.4V) | 19.5 kg·cm |
| Stall torque (12V) | 30 kg·cm |
| Voltage range | 6.0–14.0 V |
| Protocol | Half-duplex TTL serial (Feetech SCS/STS protocol), 38.4k–1Mbps |
| Connector | 5264-3P, 3-pin (GND/VCC/Signal), daisy-chain |
| Resolution | 4096 steps/rev (12-bit magnetic encoder) |
| Horn | 25T spline, OD 5.9mm |
| Mounting | 4× M3 holes on multiple faces |
| **Pocket size** | **47 × 26 × 37 mm** (0.5mm/side + tolerance) |

**Tradeoffs vs XL330:**
- Much cheaper ($8-12 vs $24)
- Much higher torque (19.5 vs 5.3 kg·cm at operating voltage)
- Much larger (45x25x35 vs 20x34x26) — too large for 250mm skeleton
- Much heavier (55g vs 18g)
- Needs separate higher voltage (7.4V+ vs 5V — can't share USB power)

**CAD file:** [GrabCAD — FEETECH_STS3215](https://grabcad.com/library/feetech_sts3215-1) (STEP, free account)
**Datasheet:** [Feetech official PDF](https://www.feetechrc.com/Data/feetechrc/upload/file/20200611/6372749961523760249976542.pdf)

---

## 2. Compute Boards

### 2.1 ESP32-S3-WROOM-1-N16R8 Custom PCB (Spark + Pro — all tiers)

| Spec | Value |
|---|---|
| Custom PCB L × W | ~55 × 35 mm (2-layer) |
| Module | ESP32-S3-WROOM-1-N16R8 (FCC modular cert, $3/unit) |
| On-board | PCA9685 (PWM servo control), MAX98357A (I2S amp), USB-C |
| Pro populates | SPH0641LU4H-1 mic, MPU6050 IMU, FSR inputs, OV2640 camera, battery circuit |
| Communication | WiFi + Bluetooth (AI offloaded to phone) |
| Servo control | PCA9685 I2C (SG90/MG90S) + UART (Dynamixel XL330, Pro) |
| **Pocket size** | **58 × 38 × 12 mm** (with standoffs + connector clearance) |

**Dev board for prototyping:** ESP32-S3-DevKitC-1

**Design note:** Same custom PCB is used for Spark and Pro. Pro simply populates additional components (mic, IMU, FSR inputs, camera connector, battery management). This keeps manufacturing simple with one board design.

---

### 2.2 Raspberry Pi 5 (4GB) (Max tier — future)

| Spec | Value |
|---|---|
| Board L × W | 85.0 × 56.0 mm |
| Height | ~21 mm (USB/Ethernet stack is tallest) |
| Mounting holes | 4× M2.5, ⌀2.7 mm, spacing 58 × 49 mm, 3.5 mm from edges |
| Weight | ~46 g |
| Connectors | 2× USB 3.0, 2× USB 2.0, 2× micro-HDMI, USB-C power, GbE RJ45, 40-pin GPIO, microSD |
| **Pocket size** | **90 × 60 × 25 mm** (with standoffs + connector clearance) |
| **Standoffs** | **4×, ⌀5 × 6mm tall, ⌀2.7 pilot hole** |

**CAD file:** [Official STEP](https://datasheets.raspberrypi.com/rpi5/raspberry-pi-5-step.zip) (direct download)
**Mechanical drawing:** [Official PDF](https://datasheets.raspberrypi.com/rpi5/raspberry-pi-5-mechanical-drawing.pdf)

**Design note:** The Pi 5 is for the Max tier only (400-500mm skeleton, future product). It does NOT fit in the 250mm Spark/Pro skeleton. Max is a separate, larger robot — not an upgrade from Spark/Pro.

---

### 2.3 PCA9685 16-Channel PWM Servo Driver (All tiers — on custom PCB)

| Spec | Value |
|---|---|
| Board L × W | 62.5 × 25.4 mm |
| Height | ~12 mm (with pin headers + screw terminals) |
| Mounting holes | 4×, ⌀2.54 mm, spacing 55.9 × 19.1 mm |
| Communication | I2C (SDA, SCL) — only 2 wires to ESP32 |
| Servo headers | 16× 3-pin (on board edge) |
| **Pocket size** | **65 × 28 × 15 mm** |
| **Standoffs** | **4×, ⌀4.5 × 3mm tall, ⌀2.5 pilot hole** |

**CAD file:** [GrabCAD — PCA9685](https://grabcad.com/library/pca9685-pwm-servo-driver-for-arduino-1)

**Placement:** Integrated on the custom ESP32-S3 PCB. Connected to ESP32 via 2-wire I2C. All PWM servo wires (SG90/MG90S) connect here.

---

## 3. Audio Components

### 3.1 Speaker — 28mm, 8Ω, 2W (All tiers)

| Spec | Value |
|---|---|
| Diameter | 28.0 mm |
| Depth | 11–12 mm |
| Cone face / baffle opening | 25 mm |
| Weight | ~8 g |
| Mounting | Friction-fit in ⌀28mm recess, or adhesive |
| **Pocket size** | **⌀29 × 13 mm** (friction fit with 0.5mm clearance + 1mm behind) |

**Placement:** Front of torso (chest area). Cut a ⌀25mm sound port through the frame wall. The shell above it should have small holes or a grille pattern for sound to escape.

**CAD file:** Simple cylinder — model as ⌀28 × 12mm disc.

---

### 3.2 MAX98357A I2S Amplifier Breakout (All tiers — on custom PCB)

| Spec | Value |
|---|---|
| Board L × W × H | 19.4 × 17.8 × 3.0 mm |
| Mounting | No mounting holes — solder header or friction-mount in slot |
| Output | 2-pin screw terminal to speaker |
| Input | I2S from ESP32 (3 wires: BCLK, LRCLK, DIN) |
| **Pocket size** | **22 × 20 × 5 mm** (with header clearance) |

**Placement:** Integrated on the custom ESP32-S3 PCB. Speaker connects via 2-pin output.

**CAD file:** Model as a 19.4 × 17.8 × 3mm block.

---

### 3.3 SPH0641LU4H-1 PDM MEMS Microphone (Pro only)

| Spec | Value |
|---|---|
| Package | LGA 3.5 × 2.65 mm, bottom-port (Knowles, LCSC C2879853, ~$1.21) |
| Height | ~1.4 mm |
| Sound port | Bottom-port — needs ⌀1mm hole in mounting surface |
| Pins | CLK + DATA (2 GPIO pins — PDM interface, ESP32-S3 has hardware PDM support) |
| Mounting | Reflow solder (production PCB) or breakout board (prototype) |
| **Pocket size** | **5 × 4 × 3 mm** (IC on custom PCB; breakout board ~14 × 14 × 3 mm) |
| **Sound hole** | **⌀1.5 mm through frame wall** |

**Placement:** Head front (face area), behind a small hole in the frame. Position at approximately mouth or chin height on the character.

---

## 4. Sensors

### 4.1 MPU6050 IMU — GY-521 Breakout (Pro only)

| Spec | Value |
|---|---|
| Board L × W × H | 21 × 16 × 3.8 mm |
| Mounting holes | 2×, ~⌀3.0 mm (M2.5/M3) |
| Pins | 8-pin header (VCC, GND, SCL, SDA, XDA, XCL, AD0, INT) |
| Communication | I2C (shares bus with PCA9685) |
| **Pocket size** | **23 × 18 × 6 mm** |
| **Standoffs** | **2×, ⌀5 × 3mm, ⌀3.0 pilot hole** |

**Placement:** Center of torso, mounted flat and level. Critical for walking balance — must be firmly attached, not vibrating. Use rubber standoffs if possible to dampen servo vibration.

**CAD file:** [GrabCAD — GY-521](https://grabcad.com/library/gy-521-mpu6050-accelerometer-and-gyroscope-module-1)

---

### 4.2 HC-SR04 Mini Ultrasonic Sensor (future — not in current Spark or Pro spec)

| Spec | Value |
|---|---|
| Board L × W × H | 40 × 18 × 15.6 mm |
| Transducer ⌀ | ~10 mm each |
| Transducer spacing | ~16 mm center-to-center |
| Voltage | 3.0–5.5 V |
| Pins | 4 (VCC, Trig, Echo, GND) |
| **Pocket size** | **42 × 20 × 17 mm** |
| **Face openings** | **2× ⌀11 mm holes** for transducers, 16mm apart |

**Placement:** Head front — the two transducers look like "eyes." The shell needs two ⌀11mm holes aligned with the transducers.

**Note:** Not included in current Spark or Pro spec. Retained for future reference. At 40x18mm this is large for a 250mm robot head. Consider the **RCWL-1601** (same pinout, slightly smaller) or a **VL53L0X ToF laser sensor** (12x18x2mm, I2C, single small lens) as a more compact alternative.

---

### 4.3 WS2812B NeoPixel LEDs (future — not in current spec)

| Spec | Value |
|---|---|
| Package (5050 SMD) | 5.0 × 5.0 × 1.6 mm |
| Through-hole (5mm) | ⌀5 mm × 8 mm tall |
| Pins | 4: VDD, GND, DIN, DOUT (daisy-chain) |
| Voltage | 3.5–5.3 V |
| Data | Single wire, daisy-chainable |
| **Pocket per LED** | **⌀6 × 3 mm** (for SMD) or **⌀5.5 × 9 mm** (through-hole) |

**Placement:**
- 2× in head (eyes) — behind ⌀5mm holes in frame, light shines through shell
- 1× in chest — behind small window in torso frame

**Note:** Not included in current Spark or Pro spec. Retained for future reference.

**Wiring:** Daisy chain: ESP32 GPIO -> LED 1 -> LED 2 -> etc. One data wire total.

---

## 5. Power Components

### 5.1 TP4056 USB-C LiPo Charging Board (Pro)

| Spec | Value |
|---|---|
| Board L × W × H | 25 × 17 × 4 mm |
| Mounting holes | 2× M2.5 |
| USB-C | Centered on short edge |
| Output | B+/B- (to battery), OUT+/OUT- (to load) |
| **Pocket size** | **27 × 19 × 6 mm** |

**Placement:** Base plate, near edge — USB-C port must be accessible through the frame and shell.

---

### 5.2 LiPo Battery 3.7V 1000mAh (Pro)

| Spec | Value |
|---|---|
| Model | 803040 (common pouch cell) |
| Dimensions | 40 × 30 × 8 mm |
| Weight | 18–20 g |
| Alt. slimmer | 502470: 70 × 24 × 5 mm, ~19 g |
| **Pocket size** | **42 × 32 × 10 mm** (with 1mm clearance + wire routing) |

**Placement:** Base plate cavity, beside or below the custom PCB. Must be removable for replacement/safety. Consider a slide-in tray.

**Safety:** Design a retaining clip or strap — LiPo should not rattle loose. Keep away from heat sources (servos under load).

---

### 5.3 USB-C Breakout Board (All tiers)

| Spec | Value |
|---|---|
| Board size | 20.4 × 14.2 × 5.0 mm (Adafruit 4090) |
| Pins | VBUS, GND, CC1, CC2, D+, D- |
| **Pocket size** | **22 × 16 × 7 mm** |

**Placement:** Base plate edge — port flush with frame exterior. Shell must have a matching cutout.

---

### 5.4 Power Switch (All tiers)

| Spec | Value |
|---|---|
| Type | Slide switch, SPDT |
| Common size | 12 × 6 × 5 mm |
| **Pocket size** | **14 × 8 × 7 mm** |

**Placement:** Base plate edge, accessible without removing shell. Toggle slot through frame + shell.

---

## 6. Skeleton Frame Dimensions (250mm)

### Updated Positions (scaled from 200mm)

| Parameter | Value | Notes |
|---|---|---|
| **Total height** | 250 mm | Base bottom to top of head servo stack |
| **Base plate** | 100 × 80 × 25 mm | Must contain ESP32-S3 custom PCB (~55×35mm) |
| **Base plate corner R** | 8 mm | |
| **Torso column** | ⌀28 mm (or 28×28 rounded rect) | Room for speaker + wiring |
| **Waist yaw servo Z** | 15 mm | Above base surface |
| **Shoulder Z** | 140 mm | ~56% of height |
| **Shoulder X** | ±48 mm | Shoulder spread from center |
| **Elbow Z** | 105 mm | Below shoulder |
| **Elbow X** | ±65 mm | Outward from shoulder |
| **Head pan Z** | 155 mm | Top of torso |
| **Head tilt Z** | 185 mm | Above pan |
| **Hip joint Z** | 0 mm | At base plate top surface |
| **Knee Z** | -60 mm | Below base |
| **Ankle Z** | -105 mm | Near ground |
| **Foot plate** | 40 × 25 × 5 mm | Each foot |

### Wire Channel Diameter

| Route | ⌀ | Notes |
|---|---|---|
| Main vertical (torso) | 8 mm | 16 servo wires + I2C + audio |
| Horizontal to shoulders | 6 mm | 2 servo cables per side |
| Leg channels | 6 mm | XL330 daisy-chain (3 wires per leg) |
| Speaker/mic wires | 4 mm | Separate from servo bundle |

---

## 7. CAD File Download Checklist

| Component | Source | Status |
|---|---|---|
| SG90 Servo | [GrabCAD](https://grabcad.com/library/sg90-micro-servo-9g-tower-pro-1) | You have this ✓ |
| MG90S Servo | [GrabCAD](https://grabcad.com/library/mg90s-servo-high-detail-1) | You have this ✓ |
| ESP32-S3 custom PCB | Custom design (KiCad) | In progress |
| Pi 5 (4GB) | [Official STEP](https://datasheets.raspberrypi.com/rpi5/raspberry-pi-5-step.zip) | Max tier only (future) |
| XL330-M288-T | [GrabCAD — XL330-288-T](https://grabcad.com/library/xl330-288-t-1) | Download needed |
| STS3215 (reference) | [GrabCAD — FEETECH_STS3215](https://grabcad.com/library/feetech_sts3215-1) | Optional — for size comparison |
| PCA9685 | [GrabCAD](https://grabcad.com/library/pca9685-pwm-servo-driver-for-arduino-1) | Download needed |
| MPU6050 GY-521 | [GrabCAD](https://grabcad.com/library/gy-521-mpu6050-accelerometer-and-gyroscope-module-1) | Download needed |
| MAX98357A | Model as 19.4 × 17.8 × 3mm block | Simple geometry |
| SPH0641LU4H-1 mic | Model as 3.5 × 2.65 × 1.4mm block (on PCB; or 14 × 14 × 3mm breakout for prototype) | Simple geometry |
| TP4056 charger | Model as 25 × 17 × 4mm block | Simple geometry |
| Speaker 28mm | Model as ⌀28 × 12mm cylinder | Simple geometry |
| LiPo battery | Model as 40 × 30 × 8mm block | Simple geometry |
| USB-C breakout | Model as 20 × 14 × 5mm block | Simple geometry |
| OV2640 camera | Model as 8 × 8 × 5mm block | Pro only |
| WS2812B LED | Model as 5 × 5 × 1.6mm block | Future — not in current spec |

---

## 8. Clearance Rules Summary

| Rule | Value | Applies to |
|---|---|---|
| Servo body clearance | 0.3 mm/side (SG90/MG90S) | All hobby servo pockets |
| Servo body clearance | 0.5 mm/side (XL330) | All Dynamixel pockets |
| Horn rotation clearance | ⌀25 mm above SG90/MG90S | Every servo with external horn |
| Horn rotation clearance | ⌀30 mm above XL330 | Leg servos |
| Board standoff height | 5–6 mm | All PCBs (airflow underneath) |
| Board perimeter clearance | 2 mm/side | Connector access + tolerance |
| Speaker front clearance | Need ⌀25mm sound hole in frame | Torso front wall |
| Mic sound hole | ⌀1.5 mm through frame | Head face |
| Wire channel minimum | ⌀4 mm | Any cable run |
| Magnet pocket | ⌀6.1 × 3.1 mm deep | All 40+ magnet positions |
| Shell clearance from frame | 1.5–3.0 mm | Depends on zone (see INTERFACE_SPEC) |
| Draft taper for shell removal | 1.5–2.0° | Along removal direction |

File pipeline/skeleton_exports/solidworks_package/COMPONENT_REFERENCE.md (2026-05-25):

# HawaBot — Component Reference & Placement Guide

Every component in the Pro skeleton with exact dimensions, mounting specifications, pocket/clearance requirements, and CAD file download links.

**Design for Pro (250mm), strip down for Core/Spark.**

---

## Quick Reference — What Goes Where

```
HEAD:
├── SG90 × 2 (pan + tilt)
├── SPH0641LU4H-1 PDM mic (face area)              Pro only
├── HC-SR04 mini ultrasonic (front, "eyes")         Pro only
└── WS2812B LEDs × 2 (eyes)                         Core+

TORSO:
├── MG90S × 2 (shoulders)
├── SG90 × 2 (elbows)                               Core+
├── SG90 × 2 (hands/grippers)                       Core+ / Pro
├── MG90S × 1 (waist yaw)
├── SG90 × 1 (waist roll)                           Core+
├── Speaker ⌀28mm (chest front)                     Core+
├── MAX98357A amp board (behind speaker)             Core+
├── WS2812B LED × 1 (chest)                          Core+
└── MPU6050 IMU (torso center)                       Pro only

BASE PLATE / HIP:
├── Raspberry Pi 5 (4GB)                             Pro (Pico W for Spark, Zero 2W for Core)
├── PCA9685 servo driver                             Core+
├── TP4056 USB-C charging board                      Pro
├── LiPo battery 3.7V 1000mAh                       Pro
├── USB-C breakout (power input)                     All tiers
└── Power switch                                     All tiers

LEGS (Pro only):
├── XL330 × 2 (hip yaw)
├── XL330 × 2 (hip pitch)
├── XL330 × 2 (knee)
├── XL330 × 2 (ankle)
└── Foot plates with rubber pads
```

---

## 1. Servos

### 1.1 SG90 Micro Servo (×7 in Pro)

**Used for:** Head pan, head tilt, L/R elbow, L/R hand grip, waist roll

| Spec | Value |
|---|---|
| Body L × W × H | 22.7 × 12.2 × 22.7 mm (body only) |
| Overall H (with shaft) | 32.3 mm |
| Tab-to-tab length | 32.3 mm |
| Tab thickness | 2.8 mm |
| Tab underside from bottom | 17.0 mm |
| Mounting holes | 2 per tab, ⌀2.0 mm, inset 2.0 mm from tab edge |
| Shaft center from front | 6.2 mm |
| Spline OD | 4.8 mm |
| Turret ⌀ | 11.8 mm |
| Turret height above body | 5.96 mm |
| Weight | 9 g |
| Torque | 1.8 kg·cm at 4.8V |
| Wire length | ~150 mm, 3-pin (signal, VCC, GND) |
| **Pocket size (with clearance)** | **23.3 × 12.8 × 23.3 mm** (body + 0.3mm/side) |
| **Tab slot size** | **32.9 × 12.8 × 3.4 mm** |
| **Turret clearance** | **⌀12.4 mm × 6.6 mm above body** |

**CAD file:** [GrabCAD — SG90](https://grabcad.com/library/sg90-micro-servo-9g-tower-pro-1) (STEP, free account)

**Clearances:**
- 0.3 mm per side around body (press fit, holds by tabs)
- Tab ledge: horizontal shelf at 17mm from bottom, servo rests on it
- Turret + horn: needs ⌀25mm × 10mm open space above body for horn rotation
- Cable exit: 4 × 6mm slot in pocket wall

---

### 1.2 MG90S Metal Gear Servo (×3 in Pro)

**Used for:** L/R shoulder, waist yaw

| Spec | Value |
|---|---|
| Body L × W × H | 22.8 × 12.4 × 22.5 mm |
| Overall H (with shaft) | 32.5 mm |
| Tab-to-tab length | 32.1 mm |
| Tab thickness | 2.8 mm |
| Tab underside from bottom | 18.5 mm |
| Mounting holes | 2 per tab, ⌀2.0 mm |
| Spline OD | 4.8 mm |
| Weight | 13.4 g |
| Torque | 2.2 kg·cm at 4.8V |
| **Pocket size (with clearance)** | **23.4 × 13.0 × 23.1 mm** |
| **Tab slot size** | **32.7 × 13.0 × 3.4 mm** |

**CAD file:** [GrabCAD — MG90S](https://grabcad.com/library/mg90s-servo-high-detail-1) (STEP, free account)

**Clearances:** Same as SG90 — 0.3mm/side, tab mounting, horn clearance.

---

### 1.3 Dynamixel XL330-M288-T (×8 in Pro — legs only)

**Used for:** L/R hip yaw, L/R hip pitch, L/R knee, L/R ankle

| Spec | Value |
|---|---|
| Body W × H × D | 20.0 × 34.0 × 26.0 mm |
| Weight | 18 g |
| Stall torque (5V) | 0.52 N·m (5.3 kg·cm) |
| Stall torque (6V) | 0.60 N·m (6.1 kg·cm) |
| Voltage range | 3.7–6.0 V (recommended 5.0V) |
| Protocol | TTL half-duplex serial, 9600–4Mbps |
| Connector | JST 3-pin (daisy-chain: 2 ports per servo) |
| Resolution | 4096 steps/rev (0.088°) |
| Gear ratio | 288.4:1 |
| Mounting | 4× M2 holes on bottom face, 8mm × 16mm pattern |
| Horn | Cross-type, 4-arm, spline: 20-tooth |
| Horn screws | M2×4 (center) |
| **Pocket size (with clearance)** | **21.0 × 35.0 × 27.0 mm** (0.5mm/side) |
| **Horn clearance above body** | **⌀30 mm × 8 mm** |

**CAD file (official):** [ROBOTIS Download Center](https://en.robotis.com/service/downloadpage.php?ca_id=70) → Drawing → DYNAMIXEL → "XL330 / XC330 / X330" → STEP
**CAD file (alt):** [GrabCAD — XL330-288-T](https://grabcad.com/library/xl330-288-t-1) (community upload)
**Datasheet:** [ROBOTIS e-Manual](https://emanual.robotis.com/docs/en/dxl/x/xl330-m288/)

**Clearances:**
- 0.5 mm per side (tighter tolerance than hobby servos — precision housing)
- Daisy-chain cable clearance: 8mm channel from servo to servo
- Horn rotation: ⌀30mm swept clear above mounting face
- M2 screw bosses: ⌀4mm posts at each mounting hole position

**Wiring note:** XL330 uses daisy-chain — each servo has 2 JST ports. Wire goes: Pi UART → first hip servo → knee → ankle. Only ONE data wire needed per leg (plus VCC + GND).

---

### 1.4 STS3215 Serial Bus Servo (alternative to XL330)

**Cheaper alternative for legs ($8-12 vs $24 per servo)**

| Spec | Value |
|---|---|
| Body L × W × H | 45.2 × 24.7 × 35.0 mm |
| Weight | 55 g |
| Stall torque (7.4V) | 19.5 kg·cm |
| Stall torque (12V) | 30 kg·cm |
| Voltage range | 6.0–14.0 V |
| Protocol | Half-duplex TTL serial (Feetech SCS/STS protocol), 38.4k–1Mbps |
| Connector | 5264-3P, 3-pin (GND/VCC/Signal), daisy-chain |
| Resolution | 4096 steps/rev (12-bit magnetic encoder) |
| Horn | 25T spline, OD 5.9mm |
| Mounting | 4× M3 holes on multiple faces |
| **Pocket size** | **47 × 26 × 37 mm** (0.5mm/side + tolerance) |

**Tradeoffs vs XL330:**
- ✓ Much cheaper ($8-12 vs $24)
- ✓ Much higher torque (19.5 vs 5.3 kg·cm at operating voltage)
- ✗ Much larger (45×25×35 vs 20×34×26)
- ✗ Much heavier (55g vs 18g)
- ✗ Needs separate higher voltage (7.4V+ vs 5V — can't share USB power)

**Recommendation:** Start with XL330 for the 250mm skeleton. STS3215 is better suited for a larger Pro skeleton (300mm+). At 250mm the STS3215 would dominate the leg cavity.

**CAD file:** [GrabCAD — FEETECH_STS3215](https://grabcad.com/library/feetech_sts3215-1) (STEP, free account)
**Datasheet:** [Feetech official PDF](https://www.feetechrc.com/Data/feetechrc/upload/file/20200611/6372749961523760249976542.pdf)

---

## 2. Compute Boards

### 2.1 Raspberry Pi Pico W (Spark tier)

| Spec | Value |
|---|---|
| Board L × W | 51.0 × 21.0 mm |
| Board thickness | 1.0 mm |
| Component height | 3.9 mm |
| Total H with headers | ~10 mm |
| Mounting holes | 4×, ⌀2.1 mm, spacing 47.0 × 11.4 mm, 2.0 mm from short edge |
| Weight | ~3 g |
| USB | Micro-USB on short edge |
| **Pocket size** | **57 × 25 × 12 mm** (with standoffs + cable space) |
| **Standoffs** | **4×, ⌀4.5 × 5mm tall, ⌀2.1 pilot hole** |

**CAD file:** [Official STEP](https://datasheets.raspberrypi.com/picow/PicoW-step.zip) (direct download, no login)

---

### 2.2 Raspberry Pi Zero 2 W (Core tier)

| Spec | Value |
|---|---|
| Board L × W | 65.0 × 30.0 mm |
| Height | ~5 mm |
| Mounting holes | 4× M2.5, ⌀2.75 mm, spacing 58 × 23 mm, 3.5 mm from edges |
| Weight | ~10 g |
| Connectors | mini-HDMI, 2× micro-USB (data + power), CSI camera, 40-pin GPIO |
| **Pocket size** | **70 × 35 × 15 mm** (with standoffs + cables) |
| **Standoffs** | **4×, ⌀5 × 5mm tall, ⌀2.75 pilot hole** |

**CAD file:** [GrabCAD](https://grabcad.com/library/raspberry-pi-zero-2-w-1) or [Geekworm Wiki STEP](https://wiki.geekworm.com/File:Raspberry-Pi-Zero-2-W.STEP)
**Mechanical drawing:** [Official PDF](https://datasheets.raspberrypi.com/rpizero2/raspberry-pi-zero-2-w-mechanical-drawing.pdf)

---

### 2.3 Raspberry Pi 5 (4GB) (Pro tier)

| Spec | Value |
|---|---|
| Board L × W | 85.0 × 56.0 mm |
| Height | ~21 mm (USB/Ethernet stack is tallest) |
| Mounting holes | 4× M2.5, ⌀2.7 mm, spacing 58 × 49 mm, 3.5 mm from edges |
| Weight | ~46 g |
| Connectors | 2× USB 3.0, 2× USB 2.0, 2× micro-HDMI, USB-C power, GbE RJ45, 40-pin GPIO, microSD |
| **Pocket size** | **90 × 60 × 25 mm** (with standoffs + connector clearance) |
| **Standoffs** | **4×, ⌀5 × 6mm tall, ⌀2.7 pilot hole** |

**CAD file:** [Official STEP](https://datasheets.raspberrypi.com/rpi5/raspberry-pi-5-step.zip) (direct download)
**Mechanical drawing:** [Official PDF](https://datasheets.raspberrypi.com/rpi5/raspberry-pi-5-mechanical-drawing.pdf)

**Design note:** The Pi 5 is BIG (85×56mm). At 250mm skeleton height with a 100×80mm base plate, it fits but dominates the base cavity. Mount flat with the USB/Ethernet ports facing one edge for access. The GPIO header should face upward or inward toward the torso wire channel.

---

### 2.4 PCA9685 16-Channel PWM Servo Driver (Core+)

| Spec | Value |
|---|---|
| Board L × W | 62.5 × 25.4 mm |
| Height | ~12 mm (with pin headers + screw terminals) |
| Mounting holes | 4×, ⌀2.54 mm, spacing 55.9 × 19.1 mm |
| Communication | I2C (SDA, SCL) — only 2 wires to Pi |
| Servo headers | 16× 3-pin (on board edge) |
| **Pocket size** | **65 × 28 × 15 mm** |
| **Standoffs** | **4×, ⌀4.5 × 3mm tall, ⌀2.5 pilot hole** |

**CAD file:** [GrabCAD — PCA9685](https://grabcad.com/library/pca9685-pwm-servo-driver-for-arduino-1)

**Placement:** Stack above or beside the Pi in the base plate. Connect to Pi via 2-wire I2C. All PWM servo wires connect here.

---

## 3. Audio Components

### 3.1 Speaker — 28mm, 8Ω, 2W (Core+)

| Spec | Value |
|---|---|
| Diameter | 28.0 mm |
| Depth | 11–12 mm |
| Cone face / baffle opening | 25 mm |
| Weight | ~8 g |
| Mounting | Friction-fit in ⌀28mm recess, or adhesive |
| **Pocket size** | **⌀29 × 13 mm** (friction fit with 0.5mm clearance + 1mm behind) |

**Placement:** Front of torso (chest area). Cut a ⌀25mm sound port through the frame wall. The shell above it should have small holes or a grille pattern for sound to escape.

**CAD file:** Simple cylinder — model as ⌀28 × 12mm disc.

---

### 3.2 MAX98357A I2S Amplifier Breakout (Core+)

| Spec | Value |
|---|---|
| Board L × W × H | 19.4 × 17.8 × 3.0 mm |
| Mounting | No mounting holes — solder header or friction-mount in slot |
| Output | 2-pin screw terminal to speaker |
| Input | I2S from Pi (3 wires: BCLK, LRCLK, DIN) |
| **Pocket size** | **22 × 20 × 5 mm** (with header clearance) |

**Placement:** Directly behind the speaker in the torso. Wire runs to Pi GPIO.

**CAD file:** Model as a 19.4 × 17.8 × 3mm block.

---
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

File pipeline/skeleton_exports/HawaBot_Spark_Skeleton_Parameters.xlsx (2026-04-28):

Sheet: Global Variables
Variable Name | SW Equation Name | Value | Description
TOLERANCES & CLEARANCES
Wall clearance | C_wall | 0.3 | Gap between servo body and cavity wall (mm)
Min shell wall | T_wall | 2.5 | Minimum printable wall thickness (mm)
Wire channel dia | D_wire | 6 | Fits 3-4 servo cables side by side (mm)
Screw hole dia | D_screw | 2 | M2 screws throughout (mm)
Snap-fit clearance | C_snap | 0.2 | Between mating snap-fit surfaces (mm)
Scale factor | S | 1 | Multiply all dims by S to resize skeleton
Section overlap | SECTION_OVERLAP | 2 | Overlap between adjacent sections (mm)
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

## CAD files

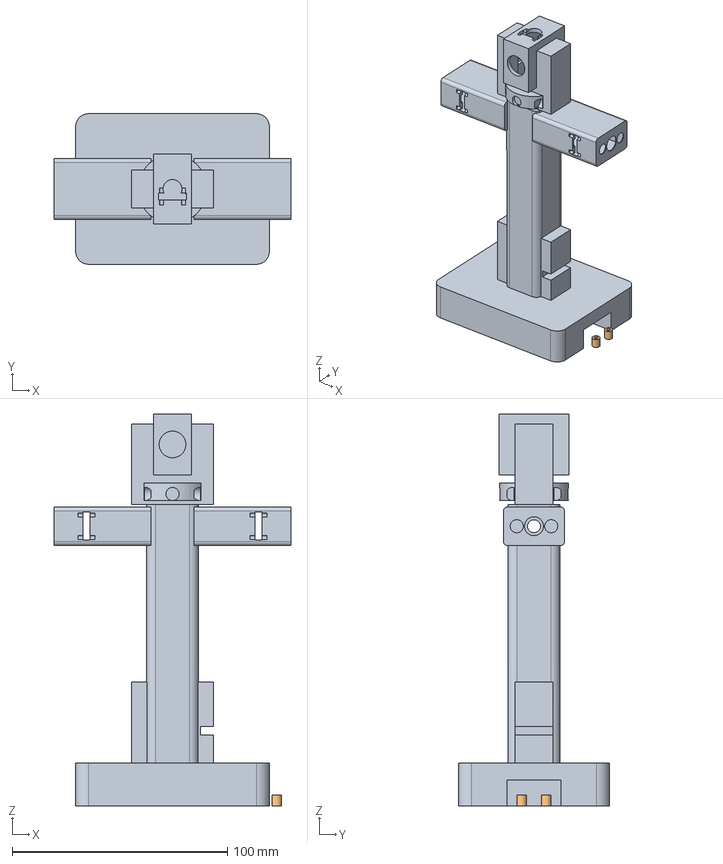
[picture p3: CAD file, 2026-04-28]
pipeline/skeleton_exports/spark_skeleton_frame.step
110.0 x 70.0 x 182.2 mm

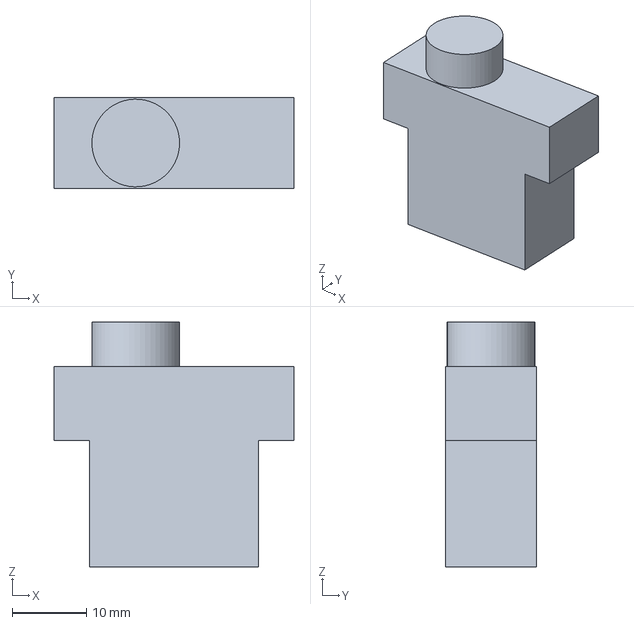
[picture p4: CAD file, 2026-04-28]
pipeline/skeleton_exports/solidworks_package/sg90_reference.step
32.3 x 12.2 x 33.0 mm

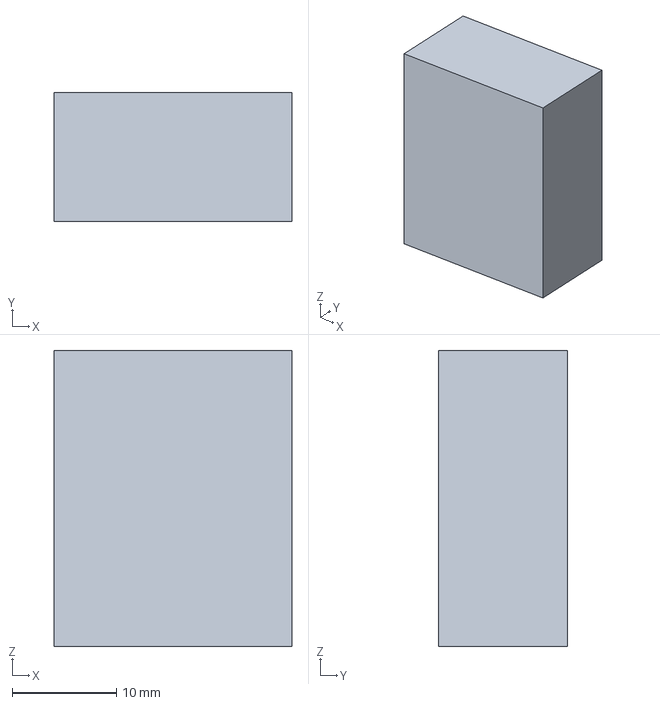
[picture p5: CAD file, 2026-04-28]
pipeline/skeleton_exports/solidworks_package/mg90s_reference.step
22.8 x 12.4 x 28.4 mm

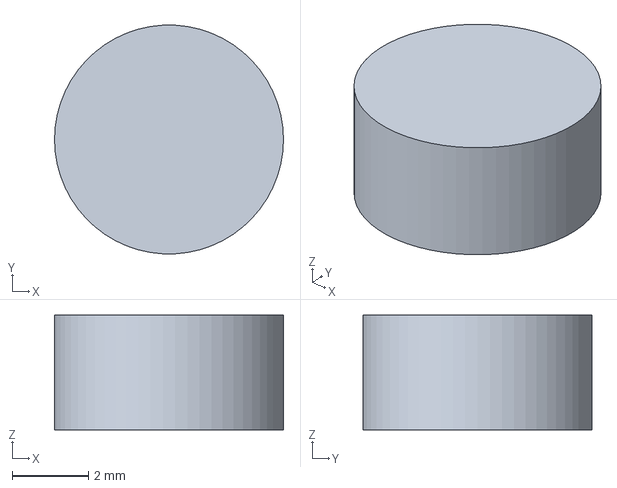
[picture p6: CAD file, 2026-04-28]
pipeline/skeleton_exports/solidworks_package/magnet_6x3_reference.step
6.00 x 5.99 x 3.00 mm

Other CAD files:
pipeline/skeleton_exports/solidworks_package/hawabot_skeleton_sketch.SLDPRT

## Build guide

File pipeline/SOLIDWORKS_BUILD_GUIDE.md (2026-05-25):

# HawaBot Pro — Kinematic Skeleton Assembly Guide (SolidWorks 2025)

Build the robot skeleton using the **Skeleton Sketch Part (SSP) method**: define all joint axes and link lengths as construction geometry first, then place real components at each joint. This enables kinematic simulation before you design any structural parts.

---

## Overview

```
Step 1: Create the Skeleton Sketch Part (SSP)
         → All joint axes, link centerlines, key planes
         → Pure construction geometry — no solid features

Step 2: Create the Master Assembly
         → Insert SSP as first (fixed) component
         → All other parts mate to SSP geometry

Step 3: Place servo components at each joint
         → Mate servo output shaft to SSP joint axis
         → Verify rotation ranges

Step 4: Place electronics, sensors, audio
         → Mate boards to SSP reference planes
         → Verify clearances

Step 5: Define magnet positions
         → Reference points on SSP for shell interface

Step 6: Run kinematic simulation
         → Motion Study using SSP mates
         → Verify joint ranges, collisions

Step 7: Design structural frame around components
         → YOUR creative work — build brackets, housings, columns
         → Reference SSP geometry so everything updates together
```

---

## Step 1: Create the Skeleton Sketch Part (SSP)

This is the most important step. The SSP contains NO solid geometry — only construction lines, planes, axes, and points that define the kinematic chain.

### 1.1 New Part

1. **File → New → Part** (mmgs template)
2. **Save As:** `hawabot_skeleton_sketch.sldprt`
3. Add all global variables via **Tools → Equations → Add** (reference `equations_250mm.txt`):

**Start with these essential variables:**
```
"TOTAL_H" = 250
"BASE_W" = 100
"BASE_D" = 80
"BASE_H" = 25
"WAIST_YAW_Z" = 15
"SHOULDER_Z" = 125
"SHOULDER_X" = 48
"SHOULDER_ROLL_X" = 55
"ELBOW_Z" = 90
"ELBOW_X" = 65
"HEAD_PAN_Z" = 155
"HEAD_TILT_Z" = 185
"HEAD_TOP_Z" = 210
"HIP_Z" = 0
"KNEE_Z" = -60
"ANKLE_Z" = -105
```

### 1.2 Master Layout Sketch — Front View (XZ Plane)

This sketch defines the kinematic chain as seen from the front.

1. Select **Front Plane** → **Insert Sketch**
2. Draw ALL of the following as **Construction Lines** (check "For construction" or select construction line mode):

**Spine chain (vertical centerline):**
```
Line 1: (0, -"BASE_H") to (0, 0)              → Base plate height
Line 2: (0, 0) to (0, "WAIST_YAW_Z")          → Ground to waist yaw
Line 3: (0, "WAIST_YAW_Z") to (0, "SHOULDER_Z")    → Waist to shoulders
Line 4: (0, "SHOULDER_Z") to (0, "HEAD_PAN_Z")      → Shoulders to neck
Line 5: (0, "HEAD_PAN_Z") to (0, "HEAD_TILT_Z")     → Head pan to tilt
Line 6: (0, "HEAD_TILT_Z") to (0, "HEAD_TOP_Z")     → Head tilt to top
```

**Left arm chain:**
```
Line 7: (0, "SHOULDER_Z") to (-"SHOULDER_X", "SHOULDER_Z")              → Shoulder pitch link
Line 8: (-"SHOULDER_X", "SHOULDER_Z") to (-"SHOULDER_ROLL_X", "SHOULDER_Z")  → Shoulder roll link
Line 9: (-"SHOULDER_ROLL_X", "SHOULDER_Z") to (-"ELBOW_X", "ELBOW_Z")  → Upper arm
Line 10: (-"ELBOW_X", "ELBOW_Z") to (-"ELBOW_X", "ELBOW_Z"-35)        → Forearm to hand
```

**Right arm chain (mirror):**
```
Line 11: (0, "SHOULDER_Z") to ("SHOULDER_X", "SHOULDER_Z")
Line 12: ("SHOULDER_X", "SHOULDER_Z") to ("SHOULDER_ROLL_X", "SHOULDER_Z")
Line 13: ("SHOULDER_ROLL_X", "SHOULDER_Z") to ("ELBOW_X", "ELBOW_Z")
Line 14: ("ELBOW_X", "ELBOW_Z") to ("ELBOW_X", "ELBOW_Z"-35)
```

**Left leg chain:**
```
Line 15: (0, "HIP_Z") to (-20, "HIP_Z")           → Hip offset
Line 16: (-20, "HIP_Z") to (-20, "KNEE_Z")         → Upper leg (thigh)
Line 17: (-20, "KNEE_Z") to (-20, "ANKLE_Z")        → Lower leg (shin)
Line 18: (-20, "ANKLE_Z") to (-20, "ANKLE_Z"-10)    → Foot
```

**Right leg chain (mirror):**
```
Line 19-22: Mirror of lines 15-18 at X = +20
```

3. **Add Construction Points** at every joint intersection — these become your joint centers:

| Point | Location | Joint Name |
|---|---|---|
| P1 | (0, 0) | Ground / base top |
| P2 | (0, 15) | Waist yaw |
| P3 | (0, 125) | Spine top / shoulder center |
| P4 | (-48, 125) | Left shoulder pitch |
| P5 | (48, 125) | Right shoulder pitch |
| P6 | (-55, 125) | Left shoulder roll |
| P7 | (55, 125) | Right shoulder roll |
| P8 | (-65, 90) | Left elbow |
| P9 | (65, 90) | Right elbow |
| P10 | (-65, 55) | Left hand |
| P11 | (65, 55) | Right hand |
| P12 | (0, 155) | Head pan |
| P13 | (0, 185) | Head tilt |
| P14 | (-20, 0) | Left hip |
| P15 | (20, 0) | Right hip |
| P16 | (-20, -60) | Left knee |
| P17 | (20, -60) | Right knee |
| P18 | (-20, -105) | Left ankle |
| P19 | (20, -105) | Right ankle |

4. **Exit Sketch**
5. **Rename** the sketch: `LAYOUT_FRONT`

### 1.3 Master Layout Sketch — Side View (YZ Plane)

1. Select **Right Plane** → **Insert Sketch**
2. Draw construction lines for the side profile:

**Spine (same Z values, Y shows front-back offset):**
```
Line: (0, -"BASE_H") to (0, "HEAD_TILT_Z")    → Full spine centerline
```

**Leg side view (shows knee bend direction):**
```
Line: (0, 0) to (0, "KNEE_Z")        → Upper leg (straight down)
Line: (0, "KNEE_Z") to (0, "ANKLE_Z") → Lower leg
```

3. **Exit Sketch** → rename `LAYOUT_SIDE`

### 1.4 Create Reference Planes for Each Joint Axis

Each servo rotation needs a **reference plane** perpendicular to its rotation axis. This is what you'll mate servo shafts to.

**Insert → Reference Geometry → Plane** for each:

| Plane Name | Definition | Joint | Rotation Axis |
|---|---|---|---|
| `PL_WAIST_YAW` | Parallel to Top Plane, offset Z = 15mm | Waist yaw | Z (vertical) |
| `PL_L_SHOULDER` | Parallel to Right Plane, through P4 (-48, 125) | L shoulder pitch | X (left-right) |
| `PL_R_SHOULDER` | Parallel to Right Plane, through P5 (48, 125) | R shoulder pitch | X (left-right) |
| `PL_L_SHOULDER_ROLL` | Parallel to Front Plane, through P6 (-55, 125) | L shoulder roll | Y (front-back) |
| `PL_R_SHOULDER_ROLL` | Parallel to Front Plane, through P7 (55, 125) | R shoulder roll | Y (front-back) |
| `PL_L_ELBOW` | Parallel to Right Plane, through P8 (-65, 90) | L elbow pitch | X |
| `PL_R_ELBOW` | Parallel to Right Plane, through P9 (65, 90) | R elbow pitch | X |
| `PL_L_HAND` | Parallel to Right Plane, through P10 (-65, 55) | L hand grip | X |
| `PL_R_HAND` | Parallel to Right Plane, through P11 (65, 55) | R hand grip | X |
| `PL_HEAD_PAN` | Parallel to Top Plane, offset Z = 155mm | Head pan yaw | Z |
| `PL_HEAD_TILT` | Parallel to Front Plane, offset Z = 185mm | Head tilt pitch | Y |
| `PL_L_HIP_YAW` | Parallel to Top Plane, through P14 (-20, 0) | L hip yaw | Z |
| `PL_R_HIP_YAW` | Parallel to Top Plane, through P15 (20, 0) | R hip yaw | Z |
| `PL_L_HIP_PITCH` | Parallel to Right Plane, through P14 | L hip pitch | X |
| `PL_R_HIP_PITCH` | Parallel to Right Plane, through P15 | R hip pitch | X |
| `PL_L_KNEE` | Parallel to Right Plane, through P16 (-20, -60) | L knee pitch | X |
| `PL_R_KNEE` | Parallel to Right Plane, through P17 (20, -60) | R knee pitch | X |
| `PL_L_ANKLE` | Parallel to Right Plane, through P18 (-20, -105) | L ankle pitch | X |
| `PL_R_ANKLE` | Parallel to Right Plane, through P19 (20, -105) | R ankle pitch | X |

### 1.5 Create Reference Axes for Each Joint

Each joint needs a **reference axis** representing the servo output shaft rotation.

**Insert → Reference Geometry → Axis** for each:

| Axis Name | Definition | Direction |
|---|---|---|
| `AX_WAIST_YAW` | Through P2, perpendicular to PL_WAIST_YAW | Vertical (Z) |
| `AX_L_SHOULDER` | Through P4, perpendicular to PL_L_SHOULDER | Left-right (X) |
| `AX_R_SHOULDER` | Through P5, perpendicular to PL_R_SHOULDER | Left-right (X) |
| `AX_L_SHOULDER_ROLL` | Through P6, perpendicular to PL_L_SHOULDER_ROLL | Front-back (Y) |
| `AX_R_SHOULDER_ROLL` | Through P7, perpendicular to PL_R_SHOULDER_ROLL | Front-back (Y) |
| `AX_L_ELBOW` | Through P8, perpendicular to PL_L_ELBOW | Left-right (X) |
| `AX_R_ELBOW` | Through P9, perpendicular to PL_R_ELBOW | Left-right (X) |
| `AX_L_HAND` | Through P10, perpendicular to PL_L_HAND | Left-right (X) |
| `AX_R_HAND` | Through P11, perpendicular to PL_R_HAND | Left-right (X) |
| `AX_HEAD_PAN` | Through P12, perpendicular to PL_HEAD_PAN | Vertical (Z) |
| `AX_HEAD_TILT` | Through P13, perpendicular to PL_HEAD_TILT | Front-back (Y) |
| `AX_L_HIP_YAW` | Through P14, perpendicular to PL_L_HIP_YAW | Vertical (Z) |
| `AX_R_HIP_YAW` | Through P15, perpendicular to PL_R_HIP_YAW | Vertical (Z) |
| `AX_L_HIP_PITCH` | Through P14, perpendicular to PL_L_HIP_PITCH | Left-right (X) |
| `AX_R_HIP_PITCH` | Through P15, perpendicular to PL_R_HIP_PITCH | Left-right (X) |
| `AX_L_KNEE` | Through P16, perpendicular to PL_L_KNEE | Left-right (X) |
| `AX_R_KNEE` | Through P17, perpendicular to PL_R_KNEE | Left-right (X) |
| `AX_L_ANKLE` | Through P18, perpendicular to PL_L_ANKLE | Left-right (X) |
| `AX_R_ANKLE` | Through P19, perpendicular to PL_R_ANKLE | Left-right (X) |

### 1.6 Create Reference Points for Component Placement

Add points for non-joint components:

| Point Name | Location (X, Y, Z) | Component |
|---|---|---|
| `PT_PCB` | (0, 0, 80) | ESP32-S3 custom PCB (~55×35mm, in torso cavity) |
| `PT_BATTERY` | (-30, 0, -12.5) | LiPo battery (Pro only) |
| `PT_TP4056` | (45, 30, -12.5) | Charging board (near base edge, Pro only) |
| `PT_USB_C` | (50, 0, -12.5) | USB-C power input (base edge) |
| `PT_SPEAKER` | (0, -14, 100) | Speaker 28mm (torso front, all tiers) |
| `PT_IMU` | (0, 0, 90) | MPU6050 IMU (torso center, Pro only) |
| `PT_MIC` | (0, -10, 175) | SPH0641LU4H-1 microphone (head, Pro only) |
| `PT_CAMERA` | (0, -12, 180) | OV2640 camera (head front, Pro only) |
| `PT_FSR_L` | (-20, 0, -115) | FSR left foot (Pro only) |
| `PT_FSR_R` | (20, 0, -115) | FSR right foot (Pro only) |

### 1.7 Save the SSP

Your SSP should now contain:
- 2 layout sketches (front + side views with all construction lines)
- 19 reference planes (one per joint — includes shoulder roll planes)
- 19 reference axes (one per joint rotation)
- ~29 reference points (19 joints + ~10 component locations)
- Global variables driving all positions
- **ZERO solid features**

Save. This part file is the **single source of truth** for your robot's geometry.

---

## Step 2: Create the Master Assembly

1. **File → New → Assembly**
2. **Save As:** `hawabot_pro_assembly.sldasm`
3. **Insert Component** → select `hawabot_skeleton_sketch.sldprt`
4. Place at origin → **Fix** the component (right-click → Fix)

The SSP is now the foundation. All other components mate to its geometry.

---

## Step 3: Place Servo Components at Each Joint

For each servo, you create two mates:
- **Concentric:** Servo output shaft axis → SSP joint axis (allows rotation)
- **Coincident:** Servo body reference plane → SSP joint plane (positions it)

### 3.1 Waist Yaw — MG90S

1. **Insert Component** → `MG90S.sldprt`
2. **Mate:**
   - Concentric: MG90S shaft axis → `AX_WAIST_YAW`
   - Coincident: MG90S mounting face → `PL_WAIST_YAW`
3. **Limit Mate** (for simulation): Set rotation limits ±90° around `AX_WAIST_YAW`
4. Servo body is below the plane, shaft points up (+Z)

### 3.2 Left Shoulder Roll — SG90

1. **Insert Component** → `SG90.sldprt`
2. **Mate:**
   - Concentric: SG90 shaft axis → `AX_L_SHOULDER_ROLL`
   - Coincident: SG90 mounting face → `PL_L_SHOULDER_ROLL`
3. **Limit Mate:** ±90°
4. Shaft points forward (+Y), outboard of shoulder pitch servo

### 3.3 Right Shoulder Roll — SG90

1. **Insert Component** → `SG90.sldprt`
2. **Mate:**
   - Concentric: SG90 shaft axis → `AX_R_SHOULDER_ROLL`
   - Coincident: SG90 mounting face → `PL_R_SHOULDER_ROLL`
3. **Limit Mate:** ±90°
4. Mirror of left shoulder roll

### 3.4 Left Shoulder Pitch — MG90S

1. **Insert Component** → `MG90S.sldprt`
2. **Mate:**
   - Concentric: shaft axis → `AX_L_SHOULDER`
   - Coincident: mounting face → `PL_L_SHOULDER`
3. **Limit Mate:** ±90°
4. Shaft points outward (-X)

### 3.5 Right Shoulder Pitch — MG90S

1. Mirror of left shoulder pitch
2. Mate to `AX_R_SHOULDER` and `PL_R_SHOULDER`
3. Shaft points outward (+X)

### 3.6 Left Elbow — SG90

1. **Insert Component** → `SG90.sldprt`
2. **Mate:**
   - Concentric: shaft axis → `AX_L_ELBOW`
   - Coincident: mounting face → `PL_L_ELBOW`
3. **Limit Mate:** ±90°

### 3.7 Right Elbow — SG90

1. Mirror of left elbow at `AX_R_ELBOW`

### 3.8 Left Hand — SG90

1. **Insert Component** → `SG90.sldprt`
2. Mate to `AX_L_HAND` / `PL_L_HAND`
3. **Limit Mate:** 0–45° (grip open to closed)

### 3.9 Right Hand — SG90

1. Mirror at `AX_R_HAND`

### 3.10 Head Pan — SG90

1. **Insert Component** → `SG90.sldprt`
2. **Mate:**
   - Concentric: shaft axis → `AX_HEAD_PAN`
   - Coincident: mounting face → `PL_HEAD_PAN`
3. **Limit Mate:** ±90°
4. Shaft points up (+Z)

### 3.11 Head Tilt — SG90

1. **Insert Component** → `SG90.sldprt`
2. **Mate:**
   - Concentric: shaft axis → `AX_HEAD_TILT`
   - Coincident: mounting face → `PL_HEAD_TILT`
3. **Limit Mate:** -30° to +30°
4. Shaft points forward (+Y)

### 3.12 Leg Servos — XL330 (×8, Pro only)

For each leg joint, insert an XL330 and mate:

| Joint | Mate Axis | Mate Plane | Limit | Shaft Direction |
|---|---|---|---|---|
| L hip yaw | `AX_L_HIP_YAW` | `PL_L_HIP_YAW` | ±45° | +Z |
| L hip pitch | `AX_L_HIP_PITCH` | `PL_L_HIP_PITCH` | ±90° | +X |
| L knee | `AX_L_KNEE` | `PL_L_KNEE` | 0° to 120° | +X |
| L ankle | `AX_L_ANKLE` | `PL_L_ANKLE` | ±30° | +X |
| R hip yaw | `AX_R_HIP_YAW` | `PL_R_HIP_YAW` | ±45° | +Z |
| R hip pitch | `AX_R_HIP_PITCH` | `PL_R_HIP_PITCH` | ±90° | +X |
| R knee | `AX_R_KNEE` | `PL_R_KNEE` | 0° to 120° | +X |
| R ankle | `AX_R_ANKLE` | `PL_R_ANKLE` | ±30° | +X |

**Important:** For daisy-chained XL330s, the cable connectors (JST 3-pin) face each other between adjacent servos. Leave 8mm cable clearance between each pair.

---

## Step 4: Place Electronics, Sensors, Audio

These components don't rotate — use **Coincident + Lock** mates to fix them at their reference points.

### 4.1 ESP32-S3 Custom PCB

1. **Insert Component** → `esp32_pcb.sldprt` (~55×35×8mm)
2. **Mate:**
   - Coincident: board center → `PT_PCB`
   - Parallel: board flat face → Top Plane
   - Lock rotation so USB-C port faces accessible edge
3. Board sits in torso cavity, 4mm standoffs from torso wall
4. Integrates: ESP32-S3-WROOM-1-N16R8, PCA9685, MAX98357A, power regulation
5. Same PCB for Spark and Pro — Pro populates additional components (mic header, IMU header, FSR inputs, camera connector, battery charging)

### 4.2 LiPo Battery (Pro only)

1. **Insert Component** → model as 40×30×8mm block
2. **Mate:** center → `PT_BATTERY`
3. Inside base plate cavity

### 4.3 TP4056 Charging Board (Pro only)

1. **Insert Component** → model as 25×17×4mm block
2. **Mate:** center → `PT_TP4056`
3. USB-C port must face base plate edge (-Y or +X)

### 4.4 USB-C Breakout

1. **Insert Component** → 20×14×5mm block
2. **Mate:** center → `PT_USB_C`
3. Port flush with base plate edge

### 4.5 Speaker (28mm)

1. **Insert Component** → ⌀28×12mm cylinder
2. **Mate:** center → `PT_SPEAKER`
3. Cone face points forward (-Y) through torso front wall

### 4.6 MPU6050 IMU (Pro only)

1. **Insert Component** → `gy521.sldprt`
2. **Mate:** center → `PT_IMU`
3. Must be level (parallel to Top Plane) and firmly mounted

### 4.7 SPH0641LU4H-1 Microphone (Pro only)

1. **Insert Component** → 14×14×3mm block
2. **Mate:** center → `PT_MIC`
3. Sound port faces forward — needs ⌀1.5mm hole through frame

### 4.8 OV2640 Camera (Pro only)

1. **Insert Component** → model as 24×24×9mm block (DVP module)
2. **Mate:** center → `PT_CAMERA`
3. Lens faces forward through frame — needs ⌀8mm clear aperture

### 4.9 FSRs — Force Sensitive Resistors (Pro only)

1. Model as ⌀14×0.5mm discs
2. **Mate** each to `PT_FSR_L` and `PT_FSR_R`
3. Placed under foot pads, wired to FSR inputs on custom PCB
4. Required for walking — provides ground contact feedback

---

## Step 5: Define Magnet Positions

Create a **3D sketch** in the SSP with construction points at all magnet locations. Reference `SKELETON_SPEC.md` § Magnet Grid for coordinates. These will later guide where you place ⌀6.1mm × 3.1mm pockets in the structural frame.

Magnet positions don't need planes or axes — just points. Group them by zone:
- Head ring: 8 points at Z≈160, radius ≈16mm
- Torso: 12 points at 3 heights around the column
- Arms: 6 points per arm on housing surfaces
- Base: 8 points around base perimeter

---

## Step 6: Run Kinematic Simulation

### 6.1 Set Up Motion Study

1. At the bottom of the SolidWorks window, click the **Motion Study** tab
2. Change type from **Animation** to **Motion Analysis** (for physics) or **Basic Motion** (for quick kinematics)
3. Each **Limit Mate** from Step 3 automatically constrains joint motion

### 6.2 Test Individual Joints

1. Right-click a Limit Mate → **Edit**
2. Drag the angle slider to verify the joint rotates correctly
3. Check that no servo bodies collide with adjacent servos

### 6.3 Define Motor Inputs

For each joint you want to test:
1. Right-click the Limit Mate → **Add Motor**
2. Set type: **Rotary Motor**
3. Apply to the concentric mate axis
4. Set motion: **Oscillate** with your desired range and speed

### 6.4 Run Collision Detection

1. In Motion Study, click **Calculate**
2. After simulation, go to **Results → Contact/Collision**
3. Identify any servo-to-servo or link-to-link collisions
4. Adjust link lengths in the SSP if needed (changes propagate to all mates)

### 6.5 Test Key Poses

Define these test positions to verify the kinematic chain:

| Pose | Joint Values | Tests |
|---|---|---|
| **T-pose** | All joints at 0° | Neutral, matches shell design |
| **Arms up** | Shoulders +90° | Max arm raise, check clearance |
| **Arms down** | Shoulders -90° | Arms alongside body |
| **Head full turn** | Pan ±90° | Neck clearance |
| **Head nod** | Tilt ±30° | Tilt clearance |
| **Waist twist** | Yaw ±90° | Upper/lower body clearance |
| **Walk step** | Hip pitch +30°, knee -60°, ankle +30° | Basic gait position |
| **Crouch** | Both hips pitch +45°, both knees -90° | Low stance |
| **Wave** | R shoulder +60°, R elbow +90° | Common animation |
| **Grip test** | Hand 0° to 45° | Gripper open/close |

---

## Step 7: Design Structural Frame

**This is YOUR design work.** With all components placed and kinematics verified, you build the 3D-printed frame around them.

### Guidelines

1. **Always reference SSP geometry** — don't dimension to servo faces, dimension to SSP planes/axes. This way, if you change a joint position in the SSP, everything updates.

2. **Build as separate part files, one per structural section:**
   - `frame_base.sldprt` — base plate, battery bay (Pro)
   - `frame_torso.sldprt` — torso column, PCB mount, speaker mount, shoulder brackets
   - `frame_head.sldprt` — head pan/tilt housing, mic mount (Pro), camera mount (Pro)
   - `frame_arm_left.sldprt` — shoulder-to-hand housing (mirror for right)
   - `frame_leg_left.sldprt` — hip-to-foot housing (mirror for right)

3. **Each structural part mates to the SSP** — not to servos or boards. The servos and boards also mate to the SSP. This keeps the reference chain clean: SSP → everything.

4. **Design pockets around components** using dimensions from `COMPONENT_REFERENCE.md`:
   - SG90 pocket: 23.3 × 12.8 × 23.3mm (body + 0.3mm/side)
   - MG90S pocket: 23.4 × 13.0 × 23.1mm
   - XL330 pocket: 21.0 × 35.0 × 27.0mm (body + 0.5mm/side)
   - ESP32-S3 custom PCB pocket: 56 × 36 × 10mm (board + standoffs)
   - Speaker recess: ⌀29 × 13mm

5. **Wire channels:** Route ⌀8mm main channel vertically through torso, ⌀6mm branches to shoulders and legs, ⌀4mm for audio/sensor wires.

6. **Magnet pockets:** Cut ⌀6.1 × 3.1mm pockets at SSP magnet reference points on all external frame surfaces.

---

## Assembly Structure Summary

```
hawabot_pro_assembly.sldasm
│
├── hawabot_skeleton_sketch.sldprt    [FIXED at origin]
│   ├── LAYOUT_FRONT (construction sketch)
│   ├── LAYOUT_SIDE (construction sketch)
│   ├── 19 Reference Planes (PL_*)
│   ├── 19 Reference Axes (AX_*)
│   ├── ~29 Reference Points (PT_*)
│   └── Global Variables (equations)
│
├── SERVOS (mate to AX_* and PL_*)
│   ├── MG90S_waist_yaw.sldprt        → AX_WAIST_YAW
│   ├── MG90S_L_shoulder.sldprt       → AX_L_SHOULDER
│   ├── MG90S_R_shoulder.sldprt       → AX_R_SHOULDER
│   ├── SG90_L_shoulder_roll.sldprt   → AX_L_SHOULDER_ROLL
│   ├── SG90_R_shoulder_roll.sldprt   → AX_R_SHOULDER_ROLL
│   ├── SG90_L_elbow.sldprt           → AX_L_ELBOW
│   ├── SG90_R_elbow.sldprt           → AX_R_ELBOW
│   ├── SG90_L_hand.sldprt            → AX_L_HAND
│   ├── SG90_R_hand.sldprt            → AX_R_HAND
│   ├── SG90_head_pan.sldprt          → AX_HEAD_PAN
│   ├── SG90_head_tilt.sldprt         → AX_HEAD_TILT
│   ├── XL330_L_hip_yaw.sldprt        → AX_L_HIP_YAW (Pro only)
│   ├── XL330_L_hip_pitch.sldprt      → AX_L_HIP_PITCH (Pro only)
│   ├── XL330_L_knee.sldprt           → AX_L_KNEE (Pro only)
│   ├── XL330_L_ankle.sldprt          → AX_L_ANKLE (Pro only)
│   ├── XL330_R_hip_yaw.sldprt        → AX_R_HIP_YAW (Pro only)
│   ├── XL330_R_hip_pitch.sldprt      → AX_R_HIP_PITCH (Pro only)
│   ├── XL330_R_knee.sldprt           → AX_R_KNEE (Pro only)
│   └── XL330_R_ankle.sldprt          → AX_R_ANKLE (Pro only)
│
├── ELECTRONICS (mate to PT_*)
│   ├── esp32_pcb.sldprt              → PT_PCB (all tiers)
│   ├── battery.sldprt                → PT_BATTERY (Pro only)
│   ├── tp4056.sldprt                 → PT_TP4056 (Pro only)
│   └── usb_c_breakout.sldprt         → PT_USB_C
│
├── AUDIO + SENSORS (mate to PT_*)
│   ├── speaker_28mm.sldprt           → PT_SPEAKER (all tiers)
│   ├── sph0641_mic.sldprt            → PT_MIC (Pro only)
│   ├── mpu6050.sldprt                → PT_IMU (Pro only)
│   ├── ov2640_camera.sldprt          → PT_CAMERA (Pro only)
│   ├── fsr_left.sldprt               → PT_FSR_L (Pro only)
│   └── fsr_right.sldprt              → PT_FSR_R (Pro only)
│
└── STRUCTURAL FRAME (YOUR DESIGN — mate to SSP)
    ├── frame_base.sldprt
    ├── frame_torso.sldprt
    ├── frame_head.sldprt
    ├── frame_arm_left.sldprt
    ├── frame_arm_right.sldprt
    ├── frame_leg_left.sldprt
    └── frame_leg_right.sldprt
```

---

## Reference Links

- [SolidWorks Skeleton Part Method (Javelin)](https://www.javelin-tech.com/blog/2017/07/solidworks-skeleton-part/)
- [Analyzing Kinematics with Layout Tools (CATI)](https://www.cati.com/blog/solidworks-analyzing-kinematics-with-2d-sketch-layout-tools/)
- [Kinematic & Dynamic Analysis (SolidWorks Blog)](https://blogs.solidworks.com/solidworksblog/2023/03/put-your-studies-in-quick-motion-with-kinematic-and-dynamic-analysis.html)
- [Poppy Humanoid CAD files (GrabCAD)](https://grabcad.com/library/poppy-humanoid-1)
- [Poppy Assembly Guide](https://docs.poppy-project.org/en/assembly-guides/poppy-humanoid/index.html)

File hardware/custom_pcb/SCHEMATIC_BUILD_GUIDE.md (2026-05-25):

# HawaBot Controller Board — Complete Schematic Build Guide

**Version:** 1.3 | **Date:** May 24, 2026 | **Author:** Hawa Labs
**This document is self-contained. No internet or Claude session required.**

---

## How to Use This Guide

Each step has three parts:
1. **DO:** Exact KiCad actions to perform
2. **VERIFY:** How to confirm it's correct
3. **EXPECTED RESULT:** What you should see if done correctly

**Do NOT proceed to the next step until all checkboxes in VERIFY are checked.**

If something doesn't match, STOP and refer to the datasheet listed for that step. All datasheets are in `hardware/custom_pcb/datasheets/`.

---

## Reference Files (Keep These Open)

| File | When to Use |
|---|---|
| `datasheets/ESP32-S3-WROOM-1.pdf` | ESP32-S3 pin assignments |
| `datasheets/PCA9685.pdf` | Servo driver pinout + reference circuit |
| `datasheets/MAX98357A.pdf` | Audio amp reference circuit |
| `datasheets/C51118_AP2112K.pdf` | LDO pinout |
| `datasheets/C16581_TP4056.pdf` | Battery charger pinout (Pro only) |
| `datasheets/C351410_DW01A.pdf` | Battery protection pinout (Pro only) |
| `datasheets/C908265_FUXINSEMI_FS8205A.pdf` | Battery MOSFET pinout (Pro only) |
| `datasheets/C7519_USBLC6.pdf` | USB ESD protection pinout |
| `datasheets/MPU6050.pdf` | IMU pinout (Pro only) |
| `datasheets/TPS61023.pdf` | Boost converter pinout + reference circuit (Pro only) |
| `datasheets/SS34_Schottky.pdf` | OR-ing diode specs (Pro only) |
| `datasheets/WS2812B.pdf` | RGB LED timing + pinout |
| `datasheets/OV2640.pdf` | Camera DVP pinout (Pro only) |
| `datasheets/C77131_TH1.pdf` | NTC thermistor specs (Pro only) |

---

## Board Overview

**Single PCB, ~60×40mm, 2-layer.** Same board for Spark and Pro — Pro populates additional components (marked DNP for Spark).

```
POWER IN (USB-C) ──► PTC fuse ──► +5V ──► D_OR1 ──►─┐
                                   │                  ├──► +5V_SERVO ──► servos
                                   └──► TP4056 (Pro)  │        │
                                          ↕           │        └──► AP2112K ──► +3V3
                                       VBAT ──► Boost │             (ESP32, PCA9685)
                                        (Pro)  5.1V ──► D_OR2 ──►─┘

CONTROL:
  ESP32-S3 ──I2C──► PCA9685 ──PWM──► 7-16 servo headers
            ──I2S──► MAX98357A ──► Speaker
            ──PDM──► SPH0641 mic (Pro DNP)
            ──I2C──► MPU6050 IMU (Pro DNP)
            ──UART──► Dynamixel bus (Pro DNP)
            ──ADC──► FSRs (Pro DNP)
            ──DVP──► OV2640 camera (Pro DNP)
```

### Component Count

| Section | Components | Populated |
|---|---|---|
| USB-C input + ESD | 8 | All tiers |
| 3.3V LDO | 3 | All tiers |
| ESP32-S3 support | 6 | All tiers |
| PCA9685 servo driver | 3 | All tiers |
| MAX98357A audio amp | 5 | All tiers |
| Servo power rail | 3 | All tiers |
| Servo headers (3-pin) | 7-16 | All tiers (7 Spark, 16 Pro) |
| Speaker + boot button | 3 | All tiers |
| TP4056 charger (Pro) | 9 | Pro only (DNP Spark) |
| DW01A/FS8205A protection (Pro) | 5 | Pro only (DNP Spark) |
| NTC thermistor (Pro) | 2 | Pro only (DNP Spark) |
| Boost converter TPS61023 (Pro) | 6 | Pro only (DNP Spark) |
| OR-ing diodes (Pro) | 2 | Pro only (DNP Spark) |
| SPH0641 mic (Pro) | 2 | Pro only (DNP Spark) |
| MPU6050 IMU (Pro) | 4 | Pro only (DNP Spark) |
| Dynamixel connector (Pro) | 1 | Pro only (DNP Spark) |
| Camera connector (Pro) | 1 | Pro only (DNP Spark) |
| FSR connectors + dividers (Pro) | 8 | Pro only (DNP Spark) |
| **TOTAL** | **~70-80** | Spark ~40, Pro ~70-80 |

---

## GPIO Pin Allocation — Master Reference

**Print this table. Reference it for every wiring step.**

| GPIO | Function | Bus/Interface | Phase | Net Label |
|---|---|---|---|---|
| 0 | BOOT button | Digital (strapping) | 1 | `BOOT` |
| 1 | FSR left front | ADC1_CH0 | 2 (Pro) | `FSR_LF` |
| 2 | FSR left rear | ADC1_CH1 | 2 (Pro) | `FSR_LR` |
| 4 | I2S0 BCLK (speaker) | I2S | 1 | `I2S_BCLK` |
| 5 | I2S0 LRCLK (speaker) | I2S | 1 | `I2S_LRCLK` |
| 6 | I2S0 DOUT (speaker) | I2S | 1 | `I2S_DOUT` |
| 7 | PDM DATA (mic) | PDM | 2 (Pro) | `PDM_DATA` |
| 8 | I2C SDA | I2C | 1 | `I2C_SDA` |
| 9 | I2C SCL | I2C | 1 | `I2C_SCL` |
| 10 | FSR right front | ADC1_CH9 | 2 (Pro) | `FSR_RF` |
| 3 | FSR right rear | ADC1_CH2 | 2 (Pro) | `FSR_RR` |
| 15 | PDM CLK (mic) | PDM | 2 (Pro) | `PDM_CLK` |
| 17 | UART1 TX (Dynamixel) | UART | 2 (Pro) | `DXL_TX` |
| 18 | UART1 RX (Dynamixel) | UART | 2 (Pro) | `DXL_RX` |
| 19 | USB D- | USB | 1 | `USB_D-` |
| 20 | USB D+ | USB | 1 | `USB_D+` |
| 43 | UART0 TX (debug) | USB-Serial | 1 | — |
| 44 | UART0 RX (debug) | USB-Serial | 1 | — |

**Reserved / Avoid:** GPIO0 (strapping, used as boot button with pull-up), GPIO45 (strapping), GPIO46 (strapping + input only). GPIO35-37 reserved for Octal SPI PSRAM on N16R8 variant — do NOT use for camera DVP or any other function.

**GPIO3 note:** Strapping pin (JTAG source select), but safe for FSR_RR with 10K pull-down. At boot, FSR reads ~0V (no force) which selects default JTAG source — no functional impact. FSR is only read during Pro walking gait, well after boot.

**ADC1 vs ADC2:** GPIO1-10 = ADC1 (works with WiFi active). GPIO11-20 = ADC2 (blocked when WiFi is active). All 4 FSRs use ADC1 pins (GPIO1, 2, 3, 10) to ensure readings work during WiFi operation.

---

# SECTION A: CORE (All Tiers — Always Populated)

---

## Setup

**DO:**
1. File → New → Project → create in `hardware/custom_pcb/kicad/hawabot_controller/`
2. Save as `hawabot_controller.kicad_sch`
3. Edit → Sheet Properties → Title: `HawaBot Controller Board V1.0`, Rev: `1.0`, Company: `Hawa Labs LLC`
4. Add custom symbol libraries: Preferences → Manage Symbol Libraries → Project tab:
   - `SPH0641` → `../SPH0641/SPH0641LU4H-1.kicad_sym`
   - `TP4056` → `../TP4056/TP4056.kicad_sym`
   - `DW01A` → `../DW01A/DW01A.kicad_sym`
   - `FS8205A` → `../FS8205-SOT236/FS8205.kicad_sym`
5. Add custom footprint libraries: Preferences → Manage Footprint Libraries → Project tab:
   - Add paths for SPH0641, TP4056, DW01A, FS8205-SOT236 folders

**VERIFY:**
- [ ] Title block shows "HawaBot Controller Board V1.0"
- [ ] All 4 custom symbol libraries load without errors (test: Place → Add Symbol → search "SPH0641" → should find it)

---

## Step 1: USB-C Input Section (8 components)

**PURPOSE:** USB-C power input with overcurrent protection, ESD protection, and data lines for programming.

**DATASHEET:** Open `datasheets/C7519_USBLC6.pdf` page 1 (pin diagram)

**DO:**
1. Place J1: `Connector:USB_C_Receptacle_USB2.0_14P`
   - Footprint: `Connector_USB:USB_C_Receptacle_HRO_TYPE-C-31-M-12`
   - LCSC: C165948
2. Place R1, R2: `Device:R` → Value: `5.1k`, Footprint: `R_0402_1005Metric`, LCSC: C25905
   - Wire: J1 CC1 → R1 → GND
   - Wire: J1 CC2 → R2 → GND
3. Place F1: `Device:Polyfuse` → Value: `1.5A`, Footprint: `R_1206_3216Metric`
   - Wire: J1 VBUS → F1 pin 1, F1 pin 2 → label `+5V`
   - **NOTE:** 1.5A rating (not 750mA like Pod) — servo current can exceed 1A
4. Place D1: `Device:D_TVS` → Value: `ESD5Z5.0T1G`, Footprint: `D_SOD-523`, LCSC: C82044
   - Wire: `+5V` to GND (clamps ESD/transient spikes)
5. Place U5: `Power_Protection:USBLC6-2SC6` → Footprint: `SOT-23-6`, LCSC: C7519
   - Wire per USBLC6 datasheet:
   - J1 D+ → U5 pin 3 (I/O2) → U5 pin 4 (I/O2) → label `USB_D+`
   - J1 D- → U5 pin 1 (I/O1) → U5 pin 6 (I/O1) → label `USB_D-`
   - U5 pin 5 (VBUS) → `+5V`
   - U5 pin 2 (GND) → GND
6. Place C1: `Device:C` → `100nF`, 0402, C1525 → between `+5V` and GND
7. Place C2: `Device:C` → `10uF`, 0805, C15850 → between `+5V` and GND

**VERIFY:**
- [ ] Power path: J1 VBUS → F1 (1.5A PTC) → `+5V` rail with D1 TVS and C1/C2 decoupling
- [ ] USB data: J1 D+/D- pass through U5 → `USB_D+`/`USB_D-` labels
- [ ] CC resistors: R1/R2 (5.1k) from CC1/CC2 to GND
- [ ] Open USBLC6 datasheet: Pin 1=I/O1(D-), Pin 2=GND, Pin 3=I/O2(D+), Pin 4=I/O2(D+), Pin 5=VBUS, Pin 6=I/O1(D-)
- [ ] F1 is rated **1.5A** (NOT 750mA)
- [ ] Component count: 8 (J1, R1, R2, F1, D1, U5, C1, C2)

**EXPECTED RESULT:** USB-C connector with overcurrent protection (F1), ESD protection (D1 + U5), CC pull-downs for power negotiation, and data lines for ESP32 programming.

---

## Step 2: 3.3V LDO (3 components)

**PURPOSE:** Regulate +5V down to +3V3 for ESP32, PCA9685 logic, and I2C sensors.

**DATASHEET:** Open `datasheets/C51118_AP2112K.pdf` page 1-2 (SOT-25 pin diagram)

**DO:**
1. Place U2: `Regulator_Linear:AP2112K-3.3` → Footprint: `SOT-23-5`, LCSC: C51118
2. Wire:

| U2 Pin | Name | Wire To |
|---|---|---|
| 1 | VIN | `+5V_SERVO` (combined power rail — USB or battery via OR-ing diodes) |
| 2 | GND | GND |
| 3 | EN | `+5V_SERVO` (tie to VIN = always enabled) |
| 4 | NC | No connect marker (X) |
| 5 | VOUT | Label `+3V3` |

**NOTE:** VIN connects to `+5V_SERVO` (NOT `+5V`). On Spark, `+5V_SERVO` = `+5V` (direct or via 0Ω jumper). On Pro, `+5V_SERVO` comes from whichever source is active (USB or battery boost) via OR-ing diodes (Step 13c). This ensures the ESP32 powers up on battery even when USB is disconnected.

3. Place C3: `Device:C` → `10uF`, 0805, C15850 → between `+5V_SERVO` (U2 VIN) and GND
4. Place C4: `Device:C` → `10uF`, 0805, C15850 → between `+3V3` (U2 VOUT) and GND

**VERIFY:**
- [ ] Pin 1 = VIN → `+5V_SERVO` (**NOT `+5V`** — must work on battery)
- [ ] Pin 3 = EN → tied to VIN (active HIGH, always enabled)
- [ ] Pin 4 = NC → no connect marker
- [ ] Pin 5 = VOUT → `+3V3`
- [ ] C3 on input, C4 on output — both to GND
- [ ] Component count: 3 (U2, C3, C4)

**EXPECTED RESULT:** 3.3V regulated output from USB 5V. Powers ESP32-S3, PCA9685 VDD, I2C bus.

---

## Step 3: ESP32-S3 Module + Support (6 components)

**PURPOSE:** Place the MCU module with boot/reset circuitry.

**DATASHEET:** Open `datasheets/ESP32-S3-WROOM-1.pdf` — pin table

**DO:**
1. Place U1: `RF_Module:ESP32-S3-WROOM-1` → Footprint: `RF_Module:ESP32-S3-WROOM-1`
   - LCSC: C2913202 (N16R8 variant — same footprint as all WROOM-1 variants)
2. Wire power:
   - U1 3V3 → `+3V3`
   - U1 GND (all GND pins) → GND
3. Wire USB:
   - U1 GPIO19 → `USB_D-` (from Step 1)
   - U1 GPIO20 → `USB_D+` (from Step 1)
4. Place R3: `Device:R` → `10k`, 0402, C25744 — EN pull-up
   - Wire: `+3V3` → R3 → U1 EN pin
5. Place C5: `Device:C` → `100nF`, 0402, C1525 — EN decoupling
   - Wire: U1 EN → C5 → GND (RC reset circuit with R3)
6. Place R4: `Device:R` → `10k`, 0402, C25744 — BOOT pull-up
   - Wire: `+3V3` → R4 → U1 GPIO0
7. Place SW1: `Switch:SW_Push` → Footprint: tactile switch, LCSC: C318884
   - Wire: U1 GPIO0 → SW1 → GND (pressing SW1 pulls GPIO0 LOW for boot mode)
8. Place SW2: `Switch:SW_Push` → Footprint: tactile switch, LCSC: C318884
   - Wire: U1 EN → SW2 → GND (pressing SW2 resets the ESP32)

**VERIFY:**
- [ ] U1 3V3 → `+3V3`, all GND pins → GND
- [ ] GPIO19 → `USB_D-`, GPIO20 → `USB_D+` — **NOT swapped** (check datasheet)
- [ ] R3 (10k) pulls EN HIGH through to +3V3
- [ ] C5 (100nF) from EN to GND — creates RC reset delay
- [ ] R4 (10k) pulls GPIO0 HIGH (normal boot)
- [ ] SW1 (BOOT) pulls GPIO0 LOW when pressed
- [ ] SW2 (RESET) pulls EN LOW when pressed — resets the ESP32
- [ ] **Boot mode entry:** hold SW1, press SW2, release SW2, release SW1
- [ ] Component count: 6 (R3, R4, C5, SW1, SW2 + U1 already placed)

**EXPECTED RESULT:** ESP32-S3 module with power, USB data, boot button (SW1), and reset button (SW2). Hold BOOT + press RESET to enter download mode.

---

## Step 4: I2C Bus (2 components)

**PURPOSE:** Shared I2C bus for PCA9685 servo driver and MPU6050 IMU (Pro).

**DO:**
1. Place R5: `Device:R` → `4.7k`, 0402, C25900 — SDA pull-up
   - Wire: `+3V3` → R5 → label `I2C_SDA`
   - Wire: U1 GPIO8 → `I2C_SDA`
2. Place R6: `Device:R` → `4.7k`, 0402, C25900 — SCL pull-up
   - Wire: `+3V3` → R6 → label `I2C_SCL`
   - Wire: U1 GPIO9 → `I2C_SCL`

**VERIFY:**
- [ ] R5 (4.7k) pulls SDA to +3V3
- [ ] R6 (4.7k) pulls SCL to +3V3
- [ ] GPIO8 = SDA, GPIO9 = SCL (matches Pod and all documentation)
- [ ] Net labels `I2C_SDA` and `I2C_SCL` placed — these will connect to PCA9685, MPU6050

**EXPECTED RESULT:** I2C bus with pull-ups. Ready for PCA9685 (Step 5) and MPU6050 (Section B).

---

## Step 5: PCA9685 Servo PWM Driver (3 components)

**PURPOSE:** 16-channel PWM driver for SG90/MG90S hobby servos. This is the core servo control IC.

**DATASHEET:** Open `datasheets/PCA9685.pdf` — page 6, Table 4 (TSSOP-28 pinout)

**CRITICAL: The PCA9685 TSSOP-28 pin numbers are NOT intuitive. Verify every pin against the datasheet. The bare IC has NO "VSERVO" pin — that is a breakout board concept.**

**PCA9685 TSSOP-28 Complete Pin Map (from datasheet Table 4):**

| Pin | Function | Pin | Function |
|-----|---|-----|---|
| 1 | A0 | 15 | LED8 |
| 2 | A1 | 16 | LED9 |
| 3 | A2 | 17 | LED10 |
| 4 | A3 | 18 | LED11 |
| 5 | A4 | 19 | LED12 |
| 6 | LED0 | 20 | LED13 |
| 7 | LED1 | 21 | LED14 |
| 8 | LED2 | 22 | LED15 |
| 9 | LED3 | 23 | OE (active LOW) |
| 10 | LED4 | 24 | A5 |
| 11 | LED5 | 25 | EXTCLK |
| 12 | LED6 | 26 | SCL |
| 13 | LED7 | 27 | SDA |
| 14 | VSS | 28 | VDD |

**DO:**
1. Place U3: `LED_Driver:PCA9685PW` → Footprint: `Package_SO:TSSOP-28_4.4x9.7mm_P0.65mm`
   - LCSC: C2678753
2. Wire power:
   - U3 VDD (**pin 28**) → `+3V3` (logic power)
   - U3 VSS (**pin 14**) → GND
3. Wire I2C:
   - U3 SDA (**pin 27**) → `I2C_SDA`
   - U3 SCL (**pin 26**) → `I2C_SCL`
4. Wire address pins (all to GND = address 0x40):
   - U3 A0 (**pin 1**) → GND
   - U3 A1 (**pin 2**) → GND
   - U3 A2 (**pin 3**) → GND
   - U3 A3 (**pin 4**) → GND
   - U3 A4 (**pin 5**) → GND
   - U3 A5 (**pin 24**) → GND
5. Wire control pins:
   - U3 OE (**pin 23**) → GND (output always enabled — OE is active LOW)
   - U3 EXTCLK (**pin 25**) → GND (use internal 25MHz oscillator — no external crystal needed)
6. Place C6: `Device:C` → `100nF`, 0402, C1525 — VDD decoupling
   - Wire: `+3V3` → C6 → GND (close to U3 VDD pin 28)
7. Place C7: `Device:C` → `10uF`, 0805, C15850 — VDD bulk
   - Wire: `+3V3` → C7 → GND

**PWM outputs (pins 6-13, 15-22) — leave FLOATING for now. Servo headers are wired in Step 7.**

**NOTE:** The PCA9685 IC has NO "VSERVO" pin. On the Adafruit breakout board, "V+" is a separate screw terminal for servo power that connects directly to servo header power pins, bypassing the IC entirely. On our custom PCB, servo 5V power goes directly from the `+5V_SERVO` rail to the servo header power pins (Step 6) — it does not pass through the PCA9685 IC at all.

**VERIFY:**
- [ ] VDD (**pin 28**) → `+3V3` — **NOT +5V**
- [ ] VSS (**pin 14**) → GND
- [ ] SDA (**pin 27**) → `I2C_SDA` — **NOT pin 23** (pin 23 is OE)
- [ ] SCL (**pin 26**) → `I2C_SCL` — **NOT pin 24** (pin 24 is A5)
- [ ] A0-A4 (**pins 1-5**) → GND — **NOT pins 17-21** (those are LED10-LED14)
- [ ] A5 (**pin 24**) → GND
- [ ] OE (**pin 23**) → GND (enabled) — **NOT pin 22** (pin 22 is LED15)
- [ ] EXTCLK (**pin 25**) → GND (internal oscillator, no crystal needed)
- [ ] **No crystal (Y1) needed** — PCA9685 has internal 25MHz oscillator. ±10% is fine for 50Hz servo PWM.
- [ ] **No "VSERVO" connection to the IC** — servo power goes to headers directly
- [ ] C6 (100nF) + C7 (10µF) decoupling on VDD
- [ ] Cross-check EVERY pin against PCA9685.pdf Table 4 (page 6)
- [ ] Component count: 3 (U3, C6, C7)

**EXPECTED RESULT:** PCA9685 connected to ESP32-S3 via I2C at address 0x40. 16 PWM outputs available. Logic at 3.3V. No crystal. Servo power handled separately in Step 6.

---

## Step 6: Servo Power Rail (3 components)

**PURPOSE:** Separate 5V high-current power rail for servos. This is critical — servos can draw 2A+ at stall and must NOT be powered through the LDO.

**DO:**
1. Create net label `+5V_SERVO`
2. **Spark (no battery):** Wire `+5V` → `+5V_SERVO` directly (or through D_OR1 if OR-ing diode pads are populated)
   **Pro (with battery):** `+5V_SERVO` is fed through OR-ing diodes from BOTH USB and boost converter — see Step 13c. For now, wire `+5V` → `+5V_SERVO` directly. Step 13c will insert OR-ing diodes.
   - **NOTE:** `+5V_SERVO` does NOT connect to any PCA9685 pin — it goes directly to servo header power pins (Step 7)
3. Place C8: `Device:C_Polarized` → `470uF`, electrolytic, ⌀8×10mm or larger
   - Wire: `+5V_SERVO` → C8+ → C8- → GND
   - **PURPOSE:** Absorbs servo inrush current spikes. Without this, servos will brown out the ESP32.
4. Place C9: `Device:C` → `100uF`, 1206, ceramic
   - Wire: `+5V_SERVO` → C9 → GND (close to servo headers)
5. Place C10: `Device:C` → `100nF`, 0402, C1525
   - Wire: `+5V_SERVO` → C10 → GND (high-frequency bypass)

**VERIFY:**
- [ ] `+5V_SERVO` connects to `+5V` (USB power) — direct, no regulator
- [ ] `+5V_SERVO` does NOT connect to any PCA9685 pin — it only goes to servo header power pins
- [ ] `+5V_SERVO` does NOT connect through the AP2112K LDO — it's direct from USB
- [ ] C8 (470µF electrolytic) is the bulk cap — largest cap on the board
- [ ] C9 (100µF ceramic) for mid-frequency filtering
- [ ] C10 (100nF) for high-frequency bypass
- [ ] All three caps between `+5V_SERVO` and GND
- [ ] Component count: 3 (C8, C9, C10)

**EXPECTED RESULT:** Robust 5V servo power rail with bulk capacitance to handle servo inrush. Servos get 5V directly from USB, not through the LDO.

---

## Step 7: Servo Headers (7-16 connectors)

**PURPOSE:** 3-pin headers for connecting hobby servos (signal, +5V, GND).

**DO:**
1. Place J_SRV0 through J_SRV6 (Spark minimum — 7 headers):
   - Symbol: `Connector_Generic:Conn_01x03`
   - Footprint: 2.54mm pitch 3-pin header
2. Wire each header:
   - Pin 1 (Signal) → PCA9685 PWM output (LED0-LED6)
   - Pin 2 (+V) → `+5V_SERVO`
   - Pin 3 (GND) → GND

**Servo channel allocation:**

| Header | PCA9685 CH | Joint | Servo | Tier |
|---|---|---|---|---|
| J_SRV0 | LED0 | head_pan | SG90 | All |
| J_SRV1 | LED1 | head_tilt | SG90 | All |
| J_SRV2 | LED2 | left_shoulder_pitch | MG90S | All |
| J_SRV3 | LED3 | left_shoulder_roll | SG90 | All |
| J_SRV4 | LED4 | right_shoulder_pitch | MG90S | All |
| J_SRV5 | LED5 | right_shoulder_roll | SG90 | All |
| J_SRV6 | LED6 | waist_yaw | MG90S | All |
| J_SRV7 | LED7 | left_elbow | SG90 | Pro |
| J_SRV8 | LED8 | left_hand | SG90 | Pro |
| J_SRV9 | LED9 | right_elbow | SG90 | Pro |
| J_SRV10 | LED10 | right_hand | SG90 | Pro |

3. For Pro, add J_SRV7 through J_SRV10 (same wiring pattern)
4. PCA9685 outputs LED11-LED15 left unconnected (available for future use)

**VERIFY:**
- [ ] Each header pin 1 (signal) connects to the correct PCA9685 LEDn output
- [ ] Each header pin 2 → `+5V_SERVO` (NOT +3V3, NOT +5V logic)
- [ ] Each header pin 3 → GND
- [ ] Minimum 7 headers for Spark, 11 for Pro
- [ ] PCA9685 LED0-LED6 → J_SRV0-J_SRV6 (always populated)
- [ ] PCA9685 LED7-LED10 → J_SRV7-J_SRV10 (Pro only, DNP Spark)

**EXPECTED RESULT:** 7-11 servo connectors, each receiving PWM from PCA9685 and power from the 5V servo rail.

---

## Step 8: MAX98357A Audio Amplifier (5 components)

**PURPOSE:** I2S Class-D mono amplifier driving a 4Ω/8Ω speaker.

**DATASHEET:** Open `datasheets/MAX98357A.pdf` — reference circuit

**DO:**
1. Place U4: search for `MAX98357AETE` or use generic opamp symbol and assign footprint
   - Footprint: `Package_DFN_QFN:QFN-16-1EP_3x3mm_P0.5mm_EP1.7x1.7mm`
   - LCSC: C910544
2. Wire:

| U4 Pin | Name | Wire To | Notes |
|---|---|---|---|
| 1 | DIN | ESP32 GPIO6 → label `I2S_DOUT` | I2S serial data |
| 2 | GAIN | GND | 9dB gain (for 4Ω speaker) |
| 3 | GND | GND | |
| 4 | SD_MODE | `+3V3` (direct or via 100k pull-up) | Shutdown + channel select. HIGH = left channel + enabled. LOW = shutdown. See pin 15 note. |
| 5-6 | OUT+ / OUT- | → Speaker connector J_SPK | Differential speaker output |
| 7 | GND | GND | |
| 8 | BCLK | ESP32 GPIO4 → label `I2S_BCLK` | I2S bit clock |
| 9 | GND | GND | |
| 10 | PVDD | `+5V` → through FB2 (ferrite bead) | Analog power — filter with ferrite |
| 11 | PVDD | Same as pin 10 | |
| 12 | GND | GND | Exposed pad |
| 13 | DVDD | `+3V3` | Digital power (1.8V internal LDO, 3.3V input OK) |
| 14 | LRCLK | ESP32 GPIO5 → label `I2S_LRCLK` | I2S word select |
| 15 | SD_MODE | Same pin as pin 4 — see above | **Pin 4 and pin 15 are the SAME function.** Wire once. |
| 16 | GND | GND | |

3. Place FB2: `Device:FerriteBead` → Value: `600R@100MHz`, 0603, LCSC: C85834
   - Wire: `+5V` → FB2 → U4 PVDD (pins 10, 11)
4. Place C11: `Device:C` → `10uF`, 0805, C15850
   - Wire: U4 PVDD (post-FB2) → C11 → GND
5. Place C12: `Device:C` → `100nF`, 0402, C1525
   - Wire: U4 DVDD (pin 13) → C12 → GND
6. Place J_SPK: `Connector_Generic:Conn_01x02` → JST-PH 2-pin
   - Wire: pin 1 → U4 OUT+, pin 2 → U4 OUT-

**VERIFY:**
- [ ] DIN (pin 1) → GPIO6 (`I2S_DOUT`) — ESP32 outputs data, MAX98357A receives
- [ ] BCLK (pin 8) → GPIO4 (`I2S_BCLK`)
- [ ] LRCLK (pin 14) → GPIO5 (`I2S_LRCLK`)
- [ ] GAIN (pin 2) → GND (9dB for 4Ω speaker)
- [ ] SD (pin 4) → HIGH (enabled). If LOW, amp is in shutdown.
- [ ] PVDD (pins 10, 11) fed through FB2 ferrite bead from +5V, with C11 (10µF) decoupling
- [ ] DVDD (pin 13) → `+3V3` with C12 (100nF) decoupling
- [ ] OUT+/OUT- → speaker connector (differential, NO ground reference on speaker)
- [ ] **Speaker wires are NOT referenced to GND** — they are differential
- [ ] Component count: 5 (FB2, C11, C12, J_SPK + U4 already placed)

**EXPECTED RESULT:** I2S audio amplifier receiving digital audio from ESP32 and driving a speaker. Powered from filtered +5V (analog) and +3V3 (digital).

---

## Step 8b: Status LEDs (4 components)

**PURPOSE:** Power indicator + firmware-controlled RGB status LED for boot mode, WiFi status, errors, OTA progress.

**DO:**

**Power LED (always on when 3.3V rail is live):**
1. Place D_PWR: `Device:LED` → GREEN, 0402, LCSC: C130723
2. Place R_PWR: `Device:R` → `1k`, 0402, C11702
3. Wire: `+3V3` → R_PWR → D_PWR anode → D_PWR cathode → GND

**Status LED (firmware-controlled RGB):**
4. Place D_STATUS: `LED:WS2812B` → Footprint: `LED_SMD:LED_WS2812B_PLCC4_5.0x5.0mm_P3.2mm`, LCSC: C2761795
5. Wire:
   - D_STATUS VDD → `+5V`
   - D_STATUS VSS → GND
   - D_STATUS DIN → ESP32 GPIO48 → label `NEOPIXEL`
   - D_STATUS DOUT → No Connect marker (single LED, no chain)
6. Place C_NEO: `Device:C` → `100nF`, 0402, C1525
   - Wire: D_STATUS VDD → C_NEO → GND (decoupling, close to LED)

**GPIO48 note:** On Pro with camera, GPIO48 is also camera SIOC (config I2C clock). Camera config happens briefly at init — LED is firmware-controlled the rest of the time. No conflict in practice.

**VERIFY:**
- [ ] D_PWR (green) lights whenever +3V3 is live — no GPIO needed
- [ ] D_STATUS (WS2812B) on GPIO48 (`NEOPIXEL`) — addressable RGB
- [ ] C_NEO (100nF) decoupling close to WS2812B VDD
- [ ] WS2812B VDD → `+5V` (NOT +3V3 — WS2812B needs 5V)
- [ ] Component count: 4 (D_PWR, R_PWR, D_STATUS, C_NEO)

**Status LED firmware color map (reference for firmware team):**

| Color | Meaning |
|---|---|
| Blue pulse | Booting / initializing |
| Green solid | WiFi connected, ready |
| Yellow pulse | OTA firmware update in progress |
| Red solid | Error / boot failure |
| White pulse | Bluetooth pairing mode |
| Off | Shutdown / deep sleep |

**EXPECTED RESULT:** Green power LED always on when board is powered. RGB status LED shows system state via firmware control.

---

## Step 9: Power Flags + Net Labels

**PURPOSE:** Prevent ERC warnings about undriven power nets.

**DO:**
1. Place `PWR_FLAG` on `+5V` net
2. Place `PWR_FLAG` on `+3V3` net
3. Place `PWR_FLAG` on `+5V_SERVO` net (if separate from `+5V`)
4. Place `PWR_FLAG` on `GND` net

**VERIFY:**
- [ ] PWR_FLAG on each power net
- [ ] No ERC "power pin not driven" warnings

---

## Step 10: Run ERC — Core Section

**DO:**
1. Inspect → Electrical Rules Check → Run

**VERIFY:**
- [ ] **Zero errors** (red)
- [ ] Warnings are only for unconnected PCA9685 LED outputs (LED11-LED15) or Pro DNP connectors
- [ ] No "different net names on same wire"
- [ ] No "power pin not driven"

**EXPECTED RESULT:** Clean ERC for the core section. Ready to add Pro components.

---

# SECTION B: PRO ONLY (DNP on Spark)

All components in this section have pads on the PCB but are NOT populated for Spark kits. Mark each with a `DNP` (Do Not Populate) note in the schematic.

---

## Step 11: TP4056 Battery Charger (9 components)

**PURPOSE:** Single-cell LiPo charging from USB-C. Identical circuit to Aerwyz Pod.

**DATASHEET:** Open `datasheets/C16581_TP4056.pdf` page 2 (pin table)

**DO:**
1. Place U6: `TP4056:TP4056` → Footprint: `TP4056:SOP127P600X175-9N`, LCSC: C16581
2. Wire pin-by-pin:

| U6 Pin | Name | Wire To |
|---|---|---|
| 1 | TEMP | NTC voltage divider (Step 12) |
| 2 | PROG | R7 (2k, C4109) → GND |
| 3 | GND | GND |
| 4 | VCC | `+5V` |
| 5 | BAT | Label `VBAT` |
| 6 | STDBY | `+5V` → D3 anode (GREEN LED) → D3 cathode → R9 (1k) → U6 pin 6 |
| 7 | CHRG | `+5V` → D2 anode (RED LED) → D2 cathode → R8 (1k) → U6 pin 7 |
| 8 | CE | `+5V` (always enabled) |
| 9 | EP | GND |

3. Place R7: 2k → PROG to GND (sets 500mA charge current)
4. Place R8, R9: 1k → LED current limiters
5. Place D2: RED LED (0402, C130719), D3: GREEN LED (0402, C130723) — charge status
6. Place C13: 10µF, 0805 → `+5V` (VCC) to GND
7. Place C14: 10µF, 0805 → `VBAT` (BAT) to GND
8. Place J_BAT: `Connector_Generic:Conn_01x02` → JST-PH 2-pin, C131337
   - Wire: J_BAT pin 1 → `VBAT`, pin 2 → GND

**VERIFY:**
- [ ] R7 = 2k → charge current = 1000/2000 = **500mA**
- [ ] Pin 7 (CHRG) drives RED LED (active-low, sinks current)
- [ ] Pin 6 (STDBY) drives GREEN LED
- [ ] LED wiring: `+5V` → LED anode → LED cathode → R → TP4056 pin (TP4056 sinks current, pins are active-LOW open-drain)
- [ ] CE (pin 8) tied to VCC (always enabled)
- [ ] C13 on VCC, C14 on BAT — both to GND
- [ ] Component count: 9 (U6, R7, R8, R9, D2, D3, C13, C14, J_BAT)

**EXPECTED RESULT:** LiPo charger that takes USB 5V, charges at 500mA, with red/green status LEDs.

---

## Step 12: NTC Battery Temperature Monitor (2 components)

**PURPOSE:** MANDATORY safety feature for CPSIA compliance with LiPo battery. Suspends charging if battery is too hot (>45°C) or too cold (<0°C).

**DO:**
1. Place TH1: NTC Thermistor, 10K B3380, 0402, LCSC: C77131
2. Place R10: `Device:R` → 10K, 0402, C25744
3. Wire the voltage divider:
   - R10: `+5V` → R10 → junction
   - TH1: junction → TH1 → GND
   - Junction → U6 pin 1 (TEMP)

```
+5V ─── R10 (10K) ─── junction ─── TH1 (10K NTC) ─── GND
                           │
                           └──→ U6 TEMP (pin 1)
```

**VERIFY:**
- [ ] TH1 is a 10K NTC thermistor (NOT a regular 10K resistor)
- [ ] Voltage divider: R10 from +5V to TEMP, TH1 from TEMP to GND
- [ ] U6 TEMP is NOT tied directly to GND
- [ ] TH1 physically placed near J_BAT (battery connector) in PCB layout
- [ ] Component count: 2 (TH1, R10)

**EXPECTED RESULT:** TP4056 suspends charging when battery temperature is outside 0-45°C range.

---

## Step 13: Battery Protection — DW01A + FS8205A (5 components)

**PURPOSE:** Protects LiPo from over-discharge (<2.4V), over-charge (>4.3V), and overcurrent.

**DATASHEET:** Open `datasheets/C351410_DW01A.pdf` page 2 and `datasheets/C908265_FUXINSEMI_FS8205A.pdf`

**CRITICAL: This step had a pin swap bug in Pod Rev 1. Follow carefully.**

**DO:**
1. Place U7: `DW01A:DW01A` → Footprint: `DW01A:SOT95P280X145-6N`, LCSC: C351410
2. Place Q1: `FS8205A:FS8205` → Footprint: `FS8205-SOT236:SOT95P280X145-6N`, LCSC: C908265
3. Place R11: `Device:R` → `100mR` (0.1 ohm), 0402, C724023
4. Place R12: `Device:R` → `100R`, 0402, C25076 — VCC inrush limiter
5. Place C15: `Device:C` → `100nF`, 0402, C1525 — VCC decoupling

Wire U7 (DW01A):

| U7 Pin | Name | Wire To |
|---|---|---|
| 1 | OD | Q1 **pin 6** (G1) — GND-side FET gate |
| 2 | VM | R11 → junction between Q1 S1 and GND (current sense / charger detect) |
| 3 | OC | Q1 **pin 4** (G2) — BAT-side FET gate |
| 4 | TD | NC or 100nF to GND |
| 5 | VCC | R12 (100R) → `VBAT` + C15 from VCC to GND |
| 6 | GND | Q1 pin 1 (S1) — NOT system GND directly |

Wire Q1 (FS8205A SOT-23-6):

| Q1 Pin | Function | Wire To |
|---|---|---|
| 1 | S1 (GND-side source) | → R11 (100mR) → GND. Also → U7 GND (pin 6) |
| 2 | D1/D2 (shared drain) | NOT connected externally |
| 3 | S2 (BAT-side source) | → `VBAT` |
| 4 | G2 (BAT-side gate) | → U7 OC (pin 3) |
| 5 | D1/D2 (shared drain) | NOT connected externally |
| 6 | G1 (GND-side gate) | → U7 OD (pin 1) |

**VERIFY — TRIPLE CHECK (Pod Rev 1 had these swapped):**
- [ ] U7 pin 1 (OD) → Q1 **pin 6** (G1). OD controls the GND-side FET.
- [ ] U7 pin 3 (OC) → Q1 **pin 4** (G2). OC controls the BAT-side FET.
- [ ] Q1 has exactly **6 pins** (SOT-23-6), NOT 8 pins
- [ ] U7 pin 6 (GND) connects to Q1 **pin 1** (S1), NOT to system GND directly
- [ ] R11 = **0.1 ohm** (100mR), NOT 1k
- [ ] R12 (100R) in series between VBAT and U7 VCC (pin 5)
- [ ] C15 (100nF) from U7 VCC to GND
- [ ] Component count: 5 (U7, Q1, R11, R12, C15)

**EXPECTED RESULT:** Battery protection that disconnects on over-discharge, over-charge, or overcurrent.

---

## Step 13b: Boost Converter — TPS61023 (6 components)

**PURPOSE:** Boost battery voltage (3.7V) to 5.1V for servo power when running on battery. Without this, servos cannot operate untethered.

**DATASHEET:** TPS61023 datasheet from TI (download from LCSC C919459 page)

**DESIGN DECISION:** Single-cell LiPo (3.7V) + boost converter. Not 2S (7.4V) + buck. Reasoning:
- TP4056 single-cell charger proven on Pod (reuse entire charging circuit)
- Single cell = lower voltage = safer for ages 12-15 (CPSIA)
- DW01A/FS8205A protection already designed for single cell
- Trade-off: lower runtime (mitigated by using 2000mAh cell)

**CRITICAL: The TPS61023 is a SYNCHRONOUS boost converter — it has an internal high-side PMOS rectifier. NO external Schottky diode needed (unlike the non-synchronous MT3608).**

**TPS61023 SOT-563 Pin Map (from datasheet Table 5-1, page 3):**

| Pin | Name | Function |
|-----|---|---|
| 1 | FB | Feedback input — connect to resistor divider |
| 2 | EN | Enable — tie to VIN for always-on |
| 3 | VIN | Power input — connect to VBAT |
| 4 | GND | Ground |
| 5 | SW | Switch node — connect inductor here |
| 6 | VOUT | Regulated output — connect to +5V_BOOST |

**DO:**
1. Place U9: `Regulator_Switching:TPS61023` (or generic boost symbol + assign footprint)
   - Footprint: SOT-563 (1.6×1.2mm, 6-pin)
   - LCSC: C919459
   - Price: ~$0.14
2. Wire per TPS61023 datasheet Figure 8-1 (Typical Application):

| U9 Pin | Name | Wire To |
|---|---|---|
| 1 | FB | Feedback divider midpoint (R17/R18) |
| 2 | EN | `VBAT` (tie to VIN = always enabled when battery present) |
| 3 | VIN | `VBAT` (from battery protection output) |
| 4 | GND | GND |
| 5 | SW | L3 inductor (other end of L3 connects to VBAT) |
| 6 | VOUT | Label `+5V_BOOST` — this IS the regulated output (internal sync rectifier) |

3. Place L3: `Device:L` → **`1µH`**, 3×3mm or 4×4mm, rated ≥4A saturation
   - Wire: `VBAT` → L3 → U9 SW (**pin 5**)
   - LCSC: Search "1uH inductor 4A" — TPS61023 datasheet Table 8-2 recommends Coilcraft XFL4020, Würth 744311100, or TDK VLC4020T
   - **NOTE:** 1µH per TI typical application (Figure 8-1). NOT 2.2µH.
4. **NO external Schottky diode** — TPS61023 is synchronous (internal PMOS rectifier). Adding one would reduce efficiency and interfere with current sensing.
5. Place C_BIN: `Device:C` → `10uF`, 0805, C15850 — boost input cap
   - Wire: `VBAT` → C_BIN → GND (close to U9 VIN, pin 3)
6. Place C_BOUT: `Device:C` → `22uF`, 0805, C45783 — boost output cap
   - Wire: `+5V_BOOST` (U9 VOUT, pin 6) → C_BOUT → GND
7. Place feedback divider (sets Vout ≈ 5.0V):
   - **TPS61023 VREF = 0.595V typical** (datasheet Section 6.5, NOT 0.5V)
   - Formula: R17 = (VOUT/VREF - 1) × R18
   - For Vout = 5.0V: R17 = (5.0/0.595 - 1) × 100k = 7.4 × 100k = **740k**
   - TI reference design (Figure 8-1) uses **R17 = 732k**, R18 = 100k → Vout ≈ 4.96V
   - Use: R17 = **750k 1%** (C137937, standard value), R18 = **100k 1%** (C25741)
   - Actual Vout = 0.595 × (1 + 750/100) = 0.595 × 8.5 = **5.06V** ✓
   - Wire: `+5V_BOOST` → R17 → junction → R18 → GND
   - Wire: junction → U9 FB (**pin 1**)

**Topology (synchronous — no external diode):**
```
VBAT ──[L3 1µH]── SW (pin 5)
  │                  │
  │                U9 TPS61023
  │                  │
  └── VIN (pin 3)  VOUT (pin 6) ── +5V_BOOST
                                      │
                                    C_BOUT (22µF)
                                      │
                           R17 (750k) ── FB (pin 1) ── R18 (100k) ── GND
```

**VERIFY:**
- [ ] **Pin 1 = FB** (NOT VIN) — feedback divider connects here
- [ ] **Pin 2 = EN** → tied to VBAT (always enabled)
- [ ] **Pin 3 = VIN** → `VBAT`
- [ ] **Pin 4 = GND** → GND
- [ ] **Pin 5 = SW** → L3 inductor (other end to VBAT)
- [ ] **Pin 6 = VOUT** → `+5V_BOOST` output
- [ ] **NO external Schottky diode** — synchronous converter handles this internally
- [ ] L3 = **1µH** (NOT 2.2µH) per TI recommendation
- [ ] L3 rated ≥ 4A saturation current (TPS61023 peaks at 3.7A)
- [ ] Feedback: R17 (**750k**) from +5V_BOOST to FB, R18 (**100k**) from FB to GND
- [ ] Vout = 0.595V × (1 + 750k/100k) = **5.06V** (within 5V ±2%)
- [ ] **VREF is 0.595V** (NOT 0.5V, NOT 0.6V) — verify in datasheet Section 6.5
- [ ] C_BIN (10µF) on VIN, C_BOUT (22µF) on VOUT
- [ ] Cross-check EVERY pin against TPS61023 datasheet Table 5-1 (page 3)
- [ ] Component count: **5** (U9, L3, C_BIN, C_BOUT, R17, R18 = 6 parts... but R17/R18 counted as 2)
- [ ] Total: 6 components (U9, L3, C_BIN, C_BOUT, R17, R18)

**EXPECTED RESULT:** When on battery (3.7V), synchronous boost converter produces ~5.06V for servos. No external diode needed. Current capability: ~1.5A continuous at 5V output from 3.7V input (2A+ in bursts with bulk caps). Efficiency ~94% at 1.5A per datasheet Figure 7-3.

---

## Step 13c: Power OR-ing Diodes (2 components)

**PURPOSE:** Merge USB 5V and boosted battery 5V into the single `+5V_SERVO` rail. Diodes prevent backfeeding between sources. Whichever source is higher voltage wins.

**DO:**
1. Place D_OR1: `Device:D_Schottky` → `SS34`, SMA, LCSC: C2480
   - Wire: anode → `+5V` (from USB input, Step 1), cathode → `+5V_SERVO`
2. Place D_OR2: `Device:D_Schottky` → `SS34`, SMA, LCSC: C2480
   - Wire: anode → `+5V_BOOST` (from boost converter, Step 13b), cathode → `+5V_SERVO`

**Update Step 6 wiring:** The `+5V_SERVO` rail is now fed through OR-ing diodes, NOT directly from `+5V`. Go back to Step 6 and change:
- **OLD:** `+5V` → `+5V_SERVO` (direct)
- **NEW:** `+5V` → D_OR1 → `+5V_SERVO` (through Schottky diode)

**Updated power architecture:**
```
USB-C (+5V) ──► D_OR1 (SS34) ──►──┐
                                    ├──► +5V_SERVO ──► servo headers + PCA9685 logic (via LDO)
VBAT (3.7V) ──► Boost (5.1V) ──► D_OR2 (SS34) ──►──┘
```

**VERIFY:**
- [ ] Both D_OR1 and D_OR2 cathodes connect to the SAME net: `+5V_SERVO`
- [ ] D_OR1 anode = `+5V` (from USB)
- [ ] D_OR2 anode = `+5V_BOOST` (from battery boost)
- [ ] Current flows FROM either source TO +5V_SERVO, but NOT back
- [ ] When USB is connected: USB 5V dominates (~5V vs boost 5.1V minus diode drop)
- [ ] When on battery only: boost 5.1V feeds servos through D_OR2
- [ ] `+5V_SERVO` is now the main 5V bus (feeds LDO input too — change U2 VIN from `+5V` to `+5V_SERVO`)
- [ ] Component count: 2 (D_OR1, D_OR2)

**NOTE:** SS34 Schottky forward drop is ~0.4-0.55V at operating currents (0.70V max at 3A per datasheet). Servo rail voltage:
- From USB (5.0V): `+5V_SERVO` ≈ 4.4-4.6V — marginal for SG90 (rated 4.8V min)
- From boost (5.06V): `+5V_SERVO` ≈ 4.5-4.7V — same concern

**Spark mitigation:** For Spark (USB-only, no battery), consider populating D_OR1 position with a **0Ω jumper** instead of Schottky diode. This gives full 5V to servos with zero drop. D_OR2 is DNP (no boost on Spark). The 0Ω jumper is safe because there's no second power source to backfeed.

**Pro:** Both diodes populated. The ~0.5V drop is acceptable because XL330 servos (Pro legs/shoulders) operate at 3.7-6V. SG90 servos at 4.5V will have slightly reduced torque (~10%) but function correctly at the light loads in this robot.

**EXPECTED RESULT:** Seamless power switching between USB and battery. Unplug USB → battery boost takes over. Plug USB back in → USB takes over and TP4056 charges battery.

---

## Step 14: SPH0641LU4H-1 PDM Microphone (2 components)

**PURPOSE:** Digital MEMS microphone for voice input. PDM interface — ESP32-S3 has hardware PDM-to-PCM converter.

**DATASHEET:** Open `datasheets/SPH0641LU4H-1.pdf` (from Pod) page 9

**DO:**
1. Place M1: `SPH0641LU4H-1:SPH0641LU4H-1`
   - Footprint: `SPH0641LU4H-1:MIC_SPH0641LU4H-1`
   - LCSC: C2879853
2. Wire:

| M1 Pin | Name | Wire To | Net Label |
|---|---|---|---|
| 1 | DATA | ESP32 GPIO7 | `PDM_DATA` |
| 2 | SELECT | GND (directly) | GND |
| 3 | GND | GND | GND |
| 4 | CLOCK | ESP32 GPIO15 | `PDM_CLK` |
| 5 | VDD | `+3V3` | `+3V3` |

3. Place C16: `Device:C` → `100nF`, 0402, C1525
   - Wire: M1 VDD (pin 5) → C16 → GND (place close to M1)

**VERIFY:**
- [ ] Pin 1 (DATA) → GPIO7 (`PDM_DATA`)
- [ ] Pin 2 (SELECT) → GND (left channel)
- [ ] Pin 3 (GND) → GND
- [ ] Pin 4 (CLOCK) → GPIO15 (`PDM_CLK`)
- [ ] Pin 5 (VDD) → `+3V3`
- [ ] C16 (100nF) decoupling on VDD
- [ ] **SELECT is NOT floating** — must be tied to GND or VDD
- [ ] Component count: 2 (M1, C16)

**EXPECTED RESULT:** PDM microphone on GPIO7 (data) and GPIO15 (clock). Only 2 GPIO pins used.

---

## Step 15: MPU6050 IMU (2 components)

**PURPOSE:** 6-axis accelerometer/gyroscope for balance sensing during walking.

**DATASHEET:** Open `datasheets/MPU6050.pdf`

**DO:**
1. Place U8: `Sensor_Motion:MPU-6050` → Footprint: `Package_DFN_QFN:QFN-24-1EP_4x4mm_P0.5mm_EP2.7x2.7mm`
   - LCSC: C24112
2. Wire:
   - U8 VDD → `+3V3`
   - U8 VLOGIC → `+3V3` (**CRITICAL** — sets I2C voltage level, must match bus voltage)
   - U8 GND → GND
   - U8 SDA → `I2C_SDA` (shared with PCA9685)
   - U8 SCL → `I2C_SCL` (shared with PCA9685)
   - U8 AD0 → GND (I2C address = 0x68)
   - U8 INT → leave unconnected or wire to a spare GPIO (optional)
   - U8 FSYNC → GND
   - U8 CLKIN → leave unconnected
   - U8 AUX_SDA, AUX_SCL → leave unconnected (no auxiliary I2C devices)
   - U8 REGOUT → C17 (100nF) → GND (internal regulator bypass)
   - U8 CPOUT → C19 (10nF) → GND (charge pump cap — **required**)
3. Place C17: 100nF, 0402, C1525 → U8 REGOUT to GND
4. Place C18: 100nF, 0402, C1525 → U8 VDD to GND (decoupling)
5. Place C19: 10nF, 0402, C15195 → U8 CPOUT to GND (charge pump)

**VERIFY:**
- [ ] VDD → `+3V3`, GND → GND
- [ ] **VLOGIC → `+3V3`** (if left floating, I2C may not work)
- [ ] SDA/SCL on same I2C bus as PCA9685
- [ ] AD0 → GND → I2C address = **0x68** (no conflict with PCA9685 at 0x40)
- [ ] FSYNC → GND
- [ ] REGOUT → C17 (100nF) → GND
- [ ] CPOUT → C19 (10nF) → GND (**required** for internal charge pump)
- [ ] Component count: 4 (C17, C18, C19 + U8)

**EXPECTED RESULT:** IMU on shared I2C bus at address 0x68. VLOGIC at 3.3V for correct I2C levels. Provides tilt and acceleration data for walking balance.

---

## Step 16: Dynamixel Bus Connector (1 component)

**PURPOSE:** Half-duplex UART connector for XL330 Dynamixel smart servos (Pro legs + shoulders).

**DO:**
1. Place J_DXL: `Connector_Generic:Conn_01x03` → JST-PH 3-pin
   - Pin 1 → `+5V_SERVO` (XL330 power, 5V)
   - Pin 2 → GND
   - Pin 3 → label `DXL_DATA`
2. Wire ESP32 UART1:
   - GPIO17 → label `DXL_TX`
   - GPIO18 → label `DXL_RX`

**NOTE:** XL330 uses half-duplex UART (single data wire). A direction-control circuit (tri-state buffer or resistor network) is needed between TX/RX and the single DXL_DATA line. For prototype, use a Robotis U2D2 adapter. For production PCB, add a 74HC126 or similar tri-state buffer.

**VERIFY:**
- [ ] J_DXL pin 1 → `+5V_SERVO` (5V power for XL330s)
- [ ] GPIO17 = TX, GPIO18 = RX (UART1)
- [ ] Half-duplex note documented in schematic

**EXPECTED RESULT:** Connector for Dynamixel servo daisy-chain. Production will need tri-state buffer for half-duplex.

---

## Step 17: Camera DVP Connector (1 component)

**PURPOSE:** FPC connector for OV2640 camera module (Pro only).

**DO:**
1. Place J_CAM: FPC connector, 24-pin, 0.5mm pitch (e.g., FH12-24S-0.5SH)
2. Wire DVP signals to ESP32 GPIOs:

**CRITICAL: GPIO35, 36, 37 are NOT available on the N16R8 variant — they are used internally for Octal SPI PSRAM. Use only GPIOs that are free on N16R8.**

| J_CAM Pin | Signal | ESP32 GPIO | Notes |
|---|---|---|---|
| — | D0 | GPIO11 | Camera is digital (not ADC) — ADC2 WiFi restriction doesn't apply |
| — | D1 | GPIO13 | |
| — | D2 | GPIO14 | |
| — | D3 | GPIO16 | Freed by PDM mic (only uses 2 pins) |
| — | D4 | GPIO21 | |
| — | D5 | GPIO38 | Safe on N16R8 |
| — | D6 | GPIO39 | |
| — | D7 | GPIO40 | |
| — | XCLK | GPIO41 | Camera master clock |
| — | PCLK | GPIO42 | Pixel clock |
| — | VSYNC | GPIO45 | **Strapping pin** — acceptable for camera (not read at boot if pulled to default) |
| — | HREF | GPIO46 | Input-only on some variants — OK for camera input |
| — | SIOD (I2C) | GPIO47 | Camera config I2C (separate bus) |
| — | SIOC (I2C) | GPIO48 | Camera config I2C (separate bus) |
| — | 3V3 | `+3V3` | |
| — | GND | GND | |

**NOTE:** Camera DVP uses 14 GPIO pins. This assignment avoids GPIO35-37 (PSRAM), GPIO3 (strapping), and does not conflict with Spark-tier functions. Camera I2C (SIOD/SIOC) is on a SEPARATE I2C bus (GPIO47/48, not GPIO8/9). Exact FPC pinout depends on camera module — verify against your specific OV2640 module before wiring.

**VERIFY:**
- [ ] Camera I2C on GPIO47/48 — **NOT on the main I2C bus** (GPIO8/9)
- [ ] **GPIO35, 36, 37 are NOT used** (reserved for PSRAM on N16R8)
- [ ] DVP data pins do not conflict with Spark-tier functions (Spark has no camera)
- [ ] 3V3 and GND connected

**EXPECTED RESULT:** Camera connector footprint on PCB, DNP for Spark.

---

## Step 18: FSR Connectors + Voltage Dividers (8 components)

**PURPOSE:** 4 Force Sensitive Resistors in feet for ground contact detection during walking.

**DO:**
1. Place 4× FSR connectors: `Connector_Generic:Conn_01x02` → JST-SH 2-pin
   - J_FSR1 (left front), J_FSR2 (left rear), J_FSR3 (right front), J_FSR4 (right rear)
2. Place 4× voltage divider resistors: R13-R16, 10k, 0402, C25744
3. Wire each FSR circuit:

```
+3V3 ─── J_FSRn pin 1 ──┬── R_n (10K) ─── GND
                          │
                          └──→ ESP32 ADC GPIO
         J_FSRn pin 2 ──→ GND
```

| FSR | Connector | Resistor | GPIO | Net Label |
|-----|---|---|---|---|
| Left front | J_FSR1 | R13 | GPIO1 | `FSR_LF` |
| Left rear | J_FSR2 | R14 | GPIO2 | `FSR_LR` |
| Right front | J_FSR3 | R15 | GPIO10 | `FSR_RF` |
| Right rear | J_FSR4 | R16 | GPIO3 | `FSR_RR` |

**VERIFY:**
- [ ] Each FSR has a 10K pull-down resistor forming a voltage divider
- [ ] All 4 FSR GPIOs are **ADC1** channels (GPIO1, 2, 3, 10) — works with WiFi active
- [ ] GPIO3 is a strapping pin but safe: 10K pull-down reads ~0V at boot (default JTAG source, no impact)
- [ ] GPIO10 is FSR_RF (ADC1). Camera D0 is on GPIO11 (separate pin, no conflict)
- [ ] FSR connectors are 2-pin (signal + GND)
- [ ] Component count: 8 (4 connectors + 4 resistors)

**EXPECTED RESULT:** 4 FSR inputs with voltage dividers, reading 0-3.3V proportional to force on each foot.

---

## Step 19: Final ERC — Full Board

**DO:**
1. Inspect → Electrical Rules Check → Run

**VERIFY:**
- [ ] **Zero errors** (red)
- [ ] All Pro DNP components properly connected (they should pass ERC even if not populated)
- [ ] No I2C address conflicts: PCA9685 = 0x40, MPU6050 = 0x68
- [ ] No GPIO conflicts (cross-reference against GPIO table at top)
- [ ] No "power pin not driven" warnings

---

## Step 20: Final Footprint Assignment & LCSC Numbers

**DO:** Tools → Edit Symbol Fields → verify every component has footprint and LCSC number.

**Complete Component Checklist:**

### Core (Always Populated) — ~45 components

| # | Ref | Value | LCSC | Section |
|---|-----|---|---|---|
| 1 | U1 | ESP32-S3-WROOM-1-N16R8 | C2913202 | Step 3 |
| 2 | U2 | AP2112K-3.3 | C51118 | Step 2 |
| 3 | U3 | PCA9685PW,118 | C2678753 | Step 5 |
| 4 | U4 | MAX98357AETE+T | C910544 | Step 8 |
| 5 | U5 | USBLC6-2SC6 | C7519 | Step 1 |
| 6 | J1 | USB-C (HRO TYPE-C-31-M-12) | C165948 | Step 1 |
| 7 | J_SPK | Speaker JST-PH 2-pin | C131337 | Step 8 |
| 8 | J_SRV0-6 | Servo headers ×7 | — | Step 7 |
| 9 | SW1 | Boot button | C318884 | Step 3 |
| 10 | SW2 | Reset button | C318884 | Step 3 |
| 11 | F1 | PTC fuse 1.5A | TBD | Step 1 |
| 12 | D1 | TVS ESD5Z5.0T1G | C82044 | Step 1 |
| 13 | D_PWR | Green power LED | C130723 | Step 8b |
| 14 | D_STATUS | WS2812B RGB | C2761795 | Step 8b |
| 15 | FB2 | Ferrite 600R | C85834 | Step 8 |
| 16 | R1-R2 | 5.1k ×2 (CC) | C25905 | Step 1 |
| 17 | R3-R4 | 10k ×2 (EN/BOOT) | C25744 | Step 3 |
| 18 | R5-R6 | 4.7k ×2 (I2C) | C25900 (both) | Step 4 |
| 19 | R_PWR | 1k (power LED) | C11702 | Step 8b |
| 20 | C1,C5,C6,C10,C12,C_NEO | 100nF ×6 | C1525 | Various |
| 21 | C2,C3,C4,C7,C11 | 10µF ×5 | C15850 | Various |
| 22 | C8 | 470µF electrolytic | TBD | Step 6 |
| 23 | C9 | 100µF ceramic | TBD | Step 6 |

### Pro Only (DNP Spark) — ~40 components

| # | Ref | Value | LCSC | Section |
|---|-----|---|---|---|
| 24 | U6 | TP4056 | C16581 | Step 11 |
| 25 | U7 | DW01A | C351410 | Step 13 |
| 26 | Q1 | FS8205A | C908265 | Step 13 |
| 27 | U8 | MPU-6050 | C24112 | Step 15 |
| 28 | U9 | TPS61023DRLR (boost) | C919459 | Step 13b |
| 29 | M1 | SPH0641LU4H-1 | C2879853 | Step 14 |
| 30 | TH1 | NTC 10K B3380 | C77131 | Step 12 |
| 31 | J_BAT | JST-PH 2-pin | C131337 | Step 11 |
| 32 | J_DXL | JST-PH 3-pin | C131334 | Step 16 |
| 33 | J_CAM | FPC 24-pin | TBD | Step 17 |
| 34 | J_FSR1-4 | JST-SH 2-pin ×4 | TBD | Step 18 |
| 35 | J_SRV7-10 | Servo headers ×4 | — | Step 7 |
| 36 | D2 | RED LED (charge) | C130719 | Step 11 |
| 37 | D3 | GREEN LED (full) | C130723 | Step 11 |
| 38 | D_OR1 | SS34 Schottky (USB) | C2480 | Step 13c |
| 39 | D_OR2 | SS34 Schottky (boost) | C2480 | Step 13c |
| 41 | L3 | 1µH inductor ≥4A | TBD | Step 13b |
| 42 | R7 | 2k (PROG) | C4109 | Step 11 |
| 43 | R8-R9 | 1k ×2 (charge LED) | C11702 | Step 11 |
| 44 | R10 | 10k (NTC bias) | C25744 | Step 12 |
| 45 | R11 | 100mR (sense) | C724023 | Step 13 |
| 46 | R12 | 100R (VCC inrush) | C25076 | Step 13 |
| 47 | R13-R16 | 10k ×4 (FSR) | C25744 | Step 18 |
| 48 | R17 | 750k 1% (boost FB top) | C137937 | Step 13b |
| 49 | R18 | 100k 1% (boost FB bottom) | C25741 | Step 13b |
| 50 | C13-C19 | Various decoupling | C1525/C15850 | Various |
| 51 | C_BIN | 10µF (boost input) | C15850 | Step 13b |
| 52 | C_BOUT | 22µF (boost output) | C45783 | Step 13b |

---

## PCB Layout Rules (Apply During Layout Phase)

These don't affect the schematic but MUST be followed during PCB layout:

### Board Outline
- Shape: Rectangle, 60 × 40 mm
- Layer count: 2
- Copper weight: 1 oz

### Antenna Keepout — CRITICAL
- ESP32-S3 antenna at one edge of the board
- **15mm no-copper zone** around antenna (no traces, no pour, no vias, no components)
- Antenna points AWAY from servo headers (toward open space)

### Power Routing
- `+5V_SERVO` traces: **1.0mm minimum** (2A+ capability)
- `+5V` traces: 0.5mm minimum
- `+3V3` traces: 0.3mm minimum
- Signal traces (I2C, I2S, PDM): 0.2mm minimum
- Ground: Pour on bottom layer (with antenna keepout)

### Component Placement
- ESP32-S3 at top edge (antenna facing outward)
- PCA9685 near center (close to servo headers)
- Servo headers along long edges (3 on one side, 4 on other)
- MAX98357A near speaker connector
- USB-C at board edge (accessible)
- Pro DNP components grouped together (bottom area)

### DRC Settings (JLCPCB compatible)
```
Minimum clearance:      0.15mm
Minimum trace width:    0.15mm
Minimum via diameter:   0.6mm
Minimum via drill:      0.3mm
Copper to edge:         0.3mm
```

Zero DRC errors required before Gerber export.

---

## Design Decisions Log

| Decision | Rationale |
|---|---|
| Single-cell LiPo + boost (not 2S + buck) | TP4056 charger + DW01A protection proven on Pod. Lower voltage = safer for kids. Full reuse of Pod charging circuit. 2000mAh cell mitigates runtime. |
| TPS61023 boost converter | 3.7A peak current, SOT-563 (tiny), $0.14 on LCSC. Handles servo loads. OR-ing diodes merge USB and battery power seamlessly. |
| WS2812B RGB status LED | Single addressable LED on GPIO48. Provides boot/WiFi/error/OTA status via firmware color codes. Same part as Pod. |
| PCA9685 internal oscillator (no crystal) | PCA9685 has EXTCLK pin (pin 25) for optional external clock, but internal 25MHz oscillator is sufficient (±10% fine for 50Hz servo PWM). No crystal needed. |
| All FSRs on ADC1 (GPIO1,2,3,10) | ADC2 (GPIO11+) is blocked when WiFi is active. FSRs must read during walking while WiFi streams to phone. GPIO3 strapping risk accepted (10K pull-down = safe boot). |
| GPIO35-37 reserved for PSRAM | N16R8 uses Octal SPI PSRAM on GPIO35-37. Camera DVP reassigned to avoid these. |
| Reset button (SW2) added | Standard ESP32 practice. Simplifies boot mode entry (hold BOOT + press RESET). Without it, must power-cycle. |
| Single-cell LiPo (not 2S) | TP4056 only charges single-cell. Simplifies power. Servos run fine on 5V from USB. |
| SPH0641 PDM mic (not INMP441 I2S) | INMP441 unavailable at LCSC. SPH0641 proven on Pod, cheaper, smaller, saves 1 GPIO pin. |
| AP2112K LDO (not AMS1117) | Proven on Pod. Lower dropout (250mV vs 1V). Same SOT-23-5 footprint. |
| Separate +5V_SERVO rail | Servo inrush can brown out ESP32 if shared. Direct USB-to-servo with bulk caps. |
| Camera I2C on separate bus (GPIO47/48) | DVP camera SCCB protocol can interfere with main I2C bus. Separate bus avoids conflicts. |

---

## Next Steps After Schematic

1. **Assign footprints** — Tools → Edit Symbol Fields → verify all footprints
2. **Export netlist** — File → Export → Netlist
3. **PCB layout** — Transfer netlist, place components per layout rules above
4. **DRC** — Zero errors before Gerber export
5. **Generate Gerbers + BOM + CPL** for JLCPCB
6. **Order prototype run** (qty 5, ~$30-50 total with assembly)

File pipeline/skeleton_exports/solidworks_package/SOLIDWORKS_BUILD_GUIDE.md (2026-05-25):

# HawaBot Pro — Kinematic Skeleton Assembly Guide (SolidWorks 2025)

Build the robot skeleton using the **Skeleton Sketch Part (SSP) method**: define all joint axes and link lengths as construction geometry first, then place real components at each joint. This enables kinematic simulation before you design any structural parts.

---

## Overview

```
Step 1: Create the Skeleton Sketch Part (SSP)
         → All joint axes, link centerlines, key planes
         → Pure construction geometry — no solid features

Step 2: Create the Master Assembly
         → Insert SSP as first (fixed) component
         → All other parts mate to SSP geometry

Step 3: Place servo components at each joint
         → Mate servo output shaft to SSP joint axis
         → Verify rotation ranges

Step 4: Place electronics, sensors, audio
         → Mate boards to SSP reference planes
         → Verify clearances

Step 5: Define magnet positions
         → Reference points on SSP for shell interface

Step 6: Run kinematic simulation
         → Motion Study using SSP mates
         → Verify joint ranges, collisions

Step 7: Design structural frame around components
         → YOUR creative work — build brackets, housings, columns
         → Reference SSP geometry so everything updates together
```

---

## Step 1: Create the Skeleton Sketch Part (SSP)

This is the most important step. The SSP contains NO solid geometry — only construction lines, planes, axes, and points that define the kinematic chain.

### 1.1 New Part

1. **File → New → Part** (mmgs template)
2. **Save As:** `hawabot_skeleton_sketch.sldprt`
3. Add all global variables via **Tools → Equations → Add** (reference `equations_250mm.txt`):

**Start with these essential variables:**
```
"TOTAL_H" = 250
"BASE_W" = 100
"BASE_D" = 80
"BASE_H" = 25
"WAIST_YAW_Z" = 15
"WAIST_ROLL_Z" = 45
"SHOULDER_Z" = 140
"SHOULDER_X" = 48
"ELBOW_Z" = 105
"ELBOW_X" = 65
"HEAD_PAN_Z" = 155
"HEAD_TILT_Z" = 185
"HIP_Z" = 0
"KNEE_Z" = -60
"ANKLE_Z" = -105
```

### 1.2 Master Layout Sketch — Front View (XZ Plane)

This sketch defines the kinematic chain as seen from the front.

1. Select **Front Plane** → **Insert Sketch**
2. Draw ALL of the following as **Construction Lines** (check "For construction" or select construction line mode):

**Spine chain (vertical centerline):**
```
Line 1: (0, -"BASE_H") to (0, 0)              → Base plate height
Line 2: (0, 0) to (0, "WAIST_YAW_Z")          → Ground to waist yaw
Line 3: (0, "WAIST_YAW_Z") to (0, "WAIST_ROLL_Z")  → Waist yaw to roll
Line 4: (0, "WAIST_ROLL_Z") to (0, "SHOULDER_Z")    → Waist to shoulders
Line 5: (0, "SHOULDER_Z") to (0, "HEAD_PAN_Z")      → Shoulders to neck
Line 6: (0, "HEAD_PAN_Z") to (0, "HEAD_TILT_Z")     → Head pan to tilt
```

**Left arm chain:**
```
Line 7: (0, "SHOULDER_Z") to (-"SHOULDER_X", "SHOULDER_Z")    → Shoulder link
Line 8: (-"SHOULDER_X", "SHOULDER_Z") to (-"ELBOW_X", "ELBOW_Z")  → Upper arm
Line 9: (-"ELBOW_X", "ELBOW_Z") to (-"ELBOW_X", "ELBOW_Z"-35)    → Forearm to hand
```

**Right arm chain (mirror):**
```
Line 10: (0, "SHOULDER_Z") to ("SHOULDER_X", "SHOULDER_Z")
Line 11: ("SHOULDER_X", "SHOULDER_Z") to ("ELBOW_X", "ELBOW_Z")
Line 12: ("ELBOW_X", "ELBOW_Z") to ("ELBOW_X", "ELBOW_Z"-35)
```

**Left leg chain:**
```
Line 13: (0, "HIP_Z") to (-20, "HIP_Z")           → Hip offset
Line 14: (-20, "HIP_Z") to (-20, "KNEE_Z")         → Upper leg (thigh)
Line 15: (-20, "KNEE_Z") to (-20, "ANKLE_Z")        → Lower leg (shin)
Line 16: (-20, "ANKLE_Z") to (-20, "ANKLE_Z"-10)    → Foot
```

**Right leg chain (mirror):**
```
Line 17-20: Mirror of lines 13-16 at X = +20
```

3. **Add Construction Points** at every joint intersection — these become your joint centers:

| Point | Location | Joint Name |
|---|---|---|
| P1 | (0, 0) | Ground / base top |
| P2 | (0, 15) | Waist yaw |
| P3 | (0, 45) | Waist roll |
| P4 | (0, 140) | Spine top / shoulder center |
| P5 | (-48, 140) | Left shoulder |
| P6 | (48, 140) | Right shoulder |
| P7 | (-65, 105) | Left elbow |
| P8 | (65, 105) | Right elbow |
| P9 | (-65, 70) | Left hand |
| P10 | (65, 70) | Right hand |
| P11 | (0, 155) | Head pan |
| P12 | (0, 185) | Head tilt |
| P13 | (-20, 0) | Left hip |
| P14 | (20, 0) | Right hip |
| P15 | (-20, -60) | Left knee |
| P16 | (20, -60) | Right knee |
| P17 | (-20, -105) | Left ankle |
| P18 | (20, -105) | Right ankle |

4. **Exit Sketch**
5. **Rename** the sketch: `LAYOUT_FRONT`

### 1.3 Master Layout Sketch — Side View (YZ Plane)

1. Select **Right Plane** → **Insert Sketch**
2. Draw construction lines for the side profile:

**Spine (same Z values, Y shows front-back offset):**
```
Line: (0, -"BASE_H") to (0, "HEAD_TILT_Z")    → Full spine centerline
```

**Leg side view (shows knee bend direction):**
```
Line: (0, 0) to (0, "KNEE_Z")        → Upper leg (straight down)
Line: (0, "KNEE_Z") to (0, "ANKLE_Z") → Lower leg
```

3. **Exit Sketch** → rename `LAYOUT_SIDE`

### 1.4 Create Reference Planes for Each Joint Axis

Each servo rotation needs a **reference plane** perpendicular to its rotation axis. This is what you'll mate servo shafts to.

**Insert → Reference Geometry → Plane** for each:

| Plane Name | Definition | Joint | Rotation Axis |
|---|---|---|---|
| `PL_WAIST_YAW` | Parallel to Top Plane, offset Z = 15mm | Waist yaw | Z (vertical) |
| `PL_WAIST_ROLL` | Parallel to Right Plane, offset Z = 45mm | Waist roll | Y (front-back) |
| `PL_L_SHOULDER` | Parallel to Right Plane, through P5 (-48, 140) | L shoulder pitch | X (left-right) |
| `PL_R_SHOULDER` | Parallel to Right Plane, through P6 (48, 140) | R shoulder pitch | X (left-right) |
| `PL_L_ELBOW` | Parallel to Right Plane, through P7 (-65, 105) | L elbow pitch | X |
| `PL_R_ELBOW` | Parallel to Right Plane, through P8 (65, 105) | R elbow pitch | X |
| `PL_L_HAND` | Parallel to Right Plane, through P9 (-65, 70) | L hand grip | X |
| `PL_R_HAND` | Parallel to Right Plane, through P10 (65, 70) | R hand grip | X |
| `PL_HEAD_PAN` | Parallel to Top Plane, offset Z = 155mm | Head pan yaw | Z |
| `PL_HEAD_TILT` | Parallel to Front Plane, offset Z = 185mm | Head tilt pitch | Y |
| `PL_L_HIP_YAW` | Parallel to Top Plane, through P13 (-20, 0) | L hip yaw | Z |
| `PL_R_HIP_YAW` | Parallel to Top Plane, through P14 (20, 0) | R hip yaw | Z |
| `PL_L_HIP_PITCH` | Parallel to Right Plane, through P13 | L hip pitch | X |
| `PL_R_HIP_PITCH` | Parallel to Right Plane, through P14 | R hip pitch | X |
| `PL_L_KNEE` | Parallel to Right Plane, through P15 (-20, -60) | L knee pitch | X |
| `PL_R_KNEE` | Parallel to Right Plane, through P16 (20, -60) | R knee pitch | X |
| `PL_L_ANKLE` | Parallel to Right Plane, through P17 (-20, -105) | L ankle pitch | X |
| `PL_R_ANKLE` | Parallel to Right Plane, through P18 (20, -105) | R ankle pitch | X |

### 1.5 Create Reference Axes for Each Joint

Each joint needs a **reference axis** representing the servo output shaft rotation.

**Insert → Reference Geometry → Axis** for each:

| Axis Name | Definition | Direction |
|---|---|---|
| `AX_WAIST_YAW` | Through P2, perpendicular to PL_WAIST_YAW | Vertical (Z) |
| `AX_WAIST_ROLL` | Through P3, perpendicular to PL_WAIST_ROLL | Front-back (Y) |
| `AX_L_SHOULDER` | Through P5, perpendicular to PL_L_SHOULDER | Left-right (X) |
| `AX_R_SHOULDER` | Through P6, perpendicular to PL_R_SHOULDER | Left-right (X) |
| `AX_L_ELBOW` | Through P7, perpendicular to PL_L_ELBOW | Left-right (X) |
| `AX_R_ELBOW` | Through P8, perpendicular to PL_R_ELBOW | Left-right (X) |
| `AX_L_HAND` | Through P9, perpendicular to PL_L_HAND | Left-right (X) |
| `AX_R_HAND` | Through P10, perpendicular to PL_R_HAND | Left-right (X) |
| `AX_HEAD_PAN` | Through P11, perpendicular to PL_HEAD_PAN | Vertical (Z) |
| `AX_HEAD_TILT` | Through P12, perpendicular to PL_HEAD_TILT | Front-back (Y) |
| `AX_L_HIP_YAW` | Through P13, perpendicular to PL_L_HIP_YAW | Vertical (Z) |
| `AX_R_HIP_YAW` | Through P14, perpendicular to PL_R_HIP_YAW | Vertical (Z) |
| `AX_L_HIP_PITCH` | Through P13, perpendicular to PL_L_HIP_PITCH | Left-right (X) |
| `AX_R_HIP_PITCH` | Through P14, perpendicular to PL_R_HIP_PITCH | Left-right (X) |
| `AX_L_KNEE` | Through P15, perpendicular to PL_L_KNEE | Left-right (X) |
| `AX_R_KNEE` | Through P16, perpendicular to PL_R_KNEE | Left-right (X) |
| `AX_L_ANKLE` | Through P17, perpendicular to PL_L_ANKLE | Left-right (X) |
| `AX_R_ANKLE` | Through P18, perpendicular to PL_R_ANKLE | Left-right (X) |

### 1.6 Create Reference Points for Component Placement

Add points for non-joint components:

| Point Name | Location (X, Y, Z) | Component |
|---|---|---|
| `PT_PI5` | (0, 0, -12.5) | Pi 5 center (inside base plate) |
| `PT_PCA9685` | (35, 0, -12.5) | PCA9685 board (beside Pi) |
| `PT_BATTERY` | (-30, 0, -12.5) | LiPo battery |
| `PT_TP4056` | (45, 30, -12.5) | Charging board (near base edge) |
| `PT_USB_C` | (50, 0, -12.5) | USB-C power input (base edge) |
| `PT_SPEAKER` | (0, -14, 100) | Speaker (torso front, chest height) |
| `PT_AMP` | (0, -8, 100) | Amp board (behind speaker) |
| `PT_IMU` | (0, 0, 90) | IMU (torso center) |
| `PT_MIC` | (0, -10, 175) | Microphone (head, face area) |
| `PT_ULTRASONIC` | (0, -12, 180) | Ultrasonic sensor (head front) |
| `PT_LED_L_EYE` | (-8, -12, 182) | Left eye LED |
| `PT_LED_R_EYE` | (8, -12, 182) | Right eye LED |
| `PT_LED_CHEST` | (0, -14, 110) | Chest LED |

### 1.7 Save the SSP

Your SSP should now contain:
- 2 layout sketches (front + side views with all construction lines)
- 18 reference planes (one per joint)
- 18 reference axes (one per joint rotation)
- ~25 reference points (joints + component locations)
- Global variables driving all positions
- **ZERO solid features**

Save. This part file is the **single source of truth** for your robot's geometry.

---

## Step 2: Create the Master Assembly

1. **File → New → Assembly**
2. **Save As:** `hawabot_pro_assembly.sldasm`
3. **Insert Component** → select `hawabot_skeleton_sketch.sldprt`
4. Place at origin → **Fix** the component (right-click → Fix)

The SSP is now the foundation. All other components mate to its geometry.

---

## Step 3: Place Servo Components at Each Joint

For each servo, you create two mates:
- **Concentric:** Servo output shaft axis → SSP joint axis (allows rotation)
- **Coincident:** Servo body reference plane → SSP joint plane (positions it)

### 3.1 Waist Yaw — MG90S

1. **Insert Component** → `MG90S.sldprt`
2. **Mate:**
   - Concentric: MG90S shaft axis → `AX_WAIST_YAW`
   - Coincident: MG90S mounting face → `PL_WAIST_YAW`
3. **Limit Mate** (for simulation): Set rotation limits ±90° around `AX_WAIST_YAW`
4. Servo body is below the plane, shaft points up (+Z)

### 3.2 Waist Roll — SG90

1. **Insert Component** → `SG90.sldprt`
2. **Mate:**
   - Concentric: SG90 shaft axis → `AX_WAIST_ROLL`
   - Coincident: SG90 mounting face → `PL_WAIST_ROLL`
3. **Limit Mate:** ±30°
4. Shaft points forward (+Y)

### 3.3 Left Shoulder — MG90S

1. **Insert Component** → `MG90S.sldprt`
2. **Mate:**
   - Concentric: shaft axis → `AX_L_SHOULDER`
   - Coincident: mounting face → `PL_L_SHOULDER`
3. **Limit Mate:** ±90°
4. Shaft points outward (-X)

### 3.4 Right Shoulder — MG90S

1. Mirror of left shoulder
2. Mate to `AX_R_SHOULDER` and `PL_R_SHOULDER`
3. Shaft points outward (+X)

### 3.5 Left Elbow — SG90

1. **Insert Component** → `SG90.sldprt`
2. **Mate:**
   - Concentric: shaft axis → `AX_L_ELBOW`
   - Coincident: mounting face → `PL_L_ELBOW`
3. **Limit Mate:** ±90°

### 3.6 Right Elbow — SG90

1. Mirror of left elbow at `AX_R_ELBOW`

### 3.7 Left Hand — SG90

1. **Insert Component** → `SG90.sldprt`
2. Mate to `AX_L_HAND` / `PL_L_HAND`
3. **Limit Mate:** 0–45° (grip open to closed)

### 3.8 Right Hand — SG90

1. Mirror at `AX_R_HAND`

### 3.9 Head Pan — SG90

1. **Insert Component** → `SG90.sldprt`
2. **Mate:**
   - Concentric: shaft axis → `AX_HEAD_PAN`
   - Coincident: mounting face → `PL_HEAD_PAN`
3. **Limit Mate:** ±90°
4. Shaft points up (+Z)

### 3.10 Head Tilt — SG90

1. **Insert Component** → `SG90.sldprt`
2. **Mate:**
   - Concentric: shaft axis → `AX_HEAD_TILT`
   - Coincident: mounting face → `PL_HEAD_TILT`
3. **Limit Mate:** -30° to +30°
4. Shaft points forward (+Y)

### 3.11 Leg Servos — XL330 (×8)

For each leg joint, insert an XL330 and mate:

| Joint | Mate Axis | Mate Plane | Limit | Shaft Direction |
|---|---|---|---|---|
| L hip yaw | `AX_L_HIP_YAW` | `PL_L_HIP_YAW` | ±45° | +Z |
| L hip pitch | `AX_L_HIP_PITCH` | `PL_L_HIP_PITCH` | ±90° | +X |
| L knee | `AX_L_KNEE` | `PL_L_KNEE` | 0° to 120° | +X |
| L ankle | `AX_L_ANKLE` | `PL_L_ANKLE` | ±30° | +X |
| R hip yaw | `AX_R_HIP_YAW` | `PL_R_HIP_YAW` | ±45° | +Z |
| R hip pitch | `AX_R_HIP_PITCH` | `PL_R_HIP_PITCH` | ±90° | +X |
| R knee | `AX_R_KNEE` | `PL_R_KNEE` | 0° to 120° | +X |
| R ankle | `AX_R_ANKLE` | `PL_R_ANKLE` | ±30° | +X |

**Important:** For daisy-chained XL330s, the cable connectors (JST 3-pin) face each other between adjacent servos. Leave 8mm cable clearance between each pair.

---

## Step 4: Place Electronics, Sensors, Audio

These components don't rotate — use **Coincident + Lock** mates to fix them at their reference points.

### 4.1 Raspberry Pi 5

1. **Insert Component** → `pi5.sldprt`
2. **Mate:**
   - Coincident: board center → `PT_PI5`
   - Parallel: board flat face → Top Plane
   - Lock rotation so USB ports face +X edge of base
3. Board sits inside base plate cavity, 6mm above base floor (standoffs)

### 4.2 PCA9685 Servo Driver

1. **Insert Component** → `pca9685.sldprt`
2. **Mate:** center → `PT_PCA9685`, parallel to Top Plane
3. Sits beside Pi 5 in base, servo headers face upward

### 4.3 LiPo Battery

1. **Insert Component** → model as 40×30×8mm block
2. **Mate:** center → `PT_BATTERY`
3. Opposite side of Pi 5 in base plate

### 4.4 TP4056 Charging Board

1. **Insert Component** → model as 25×17×4mm block
2. **Mate:** center → `PT_TP4056`
3. USB-C port must face base plate edge (-Y or +X)

### 4.5 USB-C Breakout

1. **Insert Component** → 20×14×5mm block
2. **Mate:** center → `PT_USB_C`
3. Port flush with base plate edge

### 4.6 Speaker (28mm)

1. **Insert Component** → ⌀28×12mm cylinder
2. **Mate:** center → `PT_SPEAKER`
3. Cone face points forward (-Y) through torso front wall

### 4.7 MAX98357A Amp

1. **Insert Component** → 19.4×17.8×3mm block
2. **Mate:** center → `PT_AMP`
3. Sits directly behind speaker

### 4.8 MPU6050 IMU

1. **Insert Component** → `gy521.sldprt`
2. **Mate:** center → `PT_IMU`
3. Must be level (parallel to Top Plane) and firmly mounted

### 4.9 SPH0641LU4H-1 Microphone

1. **Insert Component** → 14×14×3mm block
2. **Mate:** center → `PT_MIC`
3. Sound port faces forward — needs ⌀1.5mm hole through frame

### 4.10 HC-SR04 Mini Ultrasonic

1. **Insert Component** → 40×18×16mm block
2. **Mate:** center → `PT_ULTRASONIC`
3. Transducer faces forward — two ⌀11mm openings needed in frame

### 4.11 NeoPixel LEDs (×3)

1. Model as 5×5×2mm blocks
2. **Mate** each to `PT_LED_L_EYE`, `PT_LED_R_EYE`, `PT_LED_CHEST`
3. Light-emitting face points outward through frame

---

## Step 5: Define Magnet Positions

Create a **3D sketch** in the SSP with construction points at all magnet locations. Reference `SKELETON_SPEC.md` § Magnet Grid for coordinates. These will later guide where you place ⌀6.1mm × 3.1mm pockets in the structural frame.

Magnet positions don't need planes or axes — just points. Group them by zone:
- Head ring: 8 points at Z≈160, radius ≈16mm
- Torso: 12 points at 3 heights around the column
- Arms: 6 points per arm on housing surfaces
- Base: 8 points around base perimeter

---

## Step 6: Run Kinematic Simulation

### 6.1 Set Up Motion Study

1. At the bottom of the SolidWorks window, click the **Motion Study** tab
2. Change type from **Animation** to **Motion Analysis** (for physics) or **Basic Motion** (for quick kinematics)
3. Each **Limit Mate** from Step 3 automatically constrains joint motion

### 6.2 Test Individual Joints

1. Right-click a Limit Mate → **Edit**
2. Drag the angle slider to verify the joint rotates correctly
3. Check that no servo bodies collide with adjacent servos

### 6.3 Define Motor Inputs

For each joint you want to test:
1. Right-click the Limit Mate → **Add Motor**
2. Set type: **Rotary Motor**
3. Apply to the concentric mate axis
4. Set motion: **Oscillate** with your desired range and speed

### 6.4 Run Collision Detection

1. In Motion Study, click **Calculate**
2. After simulation, go to **Results → Contact/Collision**
3. Identify any servo-to-servo or link-to-link collisions
4. Adjust link lengths in the SSP if needed (changes propagate to all mates)

### 6.5 Test Key Poses

Define these test positions to verify the kinematic chain:

| Pose | Joint Values | Tests |
|---|---|---|
| **T-pose** | All joints at 0° | Neutral, matches shell design |
| **Arms up** | Shoulders +90° | Max arm raise, check clearance |
| **Arms down** | Shoulders -90° | Arms alongside body |
| **Head full turn** | Pan ±90° | Neck clearance |
| **Head nod** | Tilt ±30° | Tilt clearance |
| **Waist twist** | Yaw ±90° | Upper/lower body clearance |
| **Walk step** | Hip pitch +30°, knee -60°, ankle +30° | Basic gait position |
| **Crouch** | Both hips pitch +45°, both knees -90° | Low stance |
| **Wave** | R shoulder +60°, R elbow +90° | Common animation |
| **Grip test** | Hand 0° to 45° | Gripper open/close |

---

## Step 7: Design Structural Frame

**This is YOUR design work.** With all components placed and kinematics verified, you build the 3D-printed frame around them.

### Guidelines

1. **Always reference SSP geometry** — don't dimension to servo faces, dimension to SSP planes/axes. This way, if you change a joint position in the SSP, everything updates.

2. **Build as separate part files, one per structural section:**
   - `frame_base.sldprt` — base plate, Pi 5 housing, battery bay
   - `frame_torso.sldprt` — torso column, speaker mount, shoulder brackets
   - `frame_head.sldprt` — head pan/tilt housing, mic mount, sensor mount
   - `frame_arm_left.sldprt` — shoulder-to-hand housing (mirror for right)
   - `frame_leg_left.sldprt` — hip-to-foot housing (mirror for right)

3. **Each structural part mates to the SSP** — not to servos or boards. The servos and boards also mate to the SSP. This keeps the reference chain clean: SSP → everything.

4. **Design pockets around components** using dimensions from `COMPONENT_REFERENCE.md`:
   - SG90 pocket: 23.3 × 12.8 × 23.3mm (body + 0.3mm/side)
   - MG90S pocket: 23.4 × 13.0 × 23.1mm
   - XL330 pocket: 21.0 × 35.0 × 27.0mm (body + 0.5mm/side)
   - Pi 5 pocket: 90 × 60 × 25mm
   - Speaker recess: ⌀29 × 13mm

5. **Wire channels:** Route ⌀8mm main channel vertically through torso, ⌀6mm branches to shoulders and legs, ⌀4mm for audio/sensor wires.

6. **Magnet pockets:** Cut ⌀6.1 × 3.1mm pockets at SSP magnet reference points on all external frame surfaces.

---

## Assembly Structure Summary

```
hawabot_pro_assembly.sldasm
│
├── hawabot_skeleton_sketch.sldprt    [FIXED at origin]
│   ├── LAYOUT_FRONT (construction sketch)
│   ├── LAYOUT_SIDE (construction sketch)
│   ├── 18 Reference Planes (PL_*)
│   ├── 18 Reference Axes (AX_*)
│   ├── ~25 Reference Points (PT_*)
│   └── Global Variables (equations)
│
├── SERVOS (mate to AX_* and PL_*)
│   ├── MG90S_waist_yaw.sldprt        → AX_WAIST_YAW
│   ├── SG90_waist_roll.sldprt        → AX_WAIST_ROLL
│   ├── MG90S_L_shoulder.sldprt       → AX_L_SHOULDER
│   ├── MG90S_R_shoulder.sldprt       → AX_R_SHOULDER
│   ├── SG90_L_elbow.sldprt           → AX_L_ELBOW
│   ├── SG90_R_elbow.sldprt           → AX_R_ELBOW
│   ├── SG90_L_hand.sldprt            → AX_L_HAND
│   ├── SG90_R_hand.sldprt            → AX_R_HAND
│   ├── SG90_head_pan.sldprt          → AX_HEAD_PAN
│   ├── SG90_head_tilt.sldprt         → AX_HEAD_TILT
│   ├── XL330_L_hip_yaw.sldprt        → AX_L_HIP_YAW
│   ├── XL330_L_hip_pitch.sldprt      → AX_L_HIP_PITCH
│   ├── XL330_L_knee.sldprt           → AX_L_KNEE
│   ├── XL330_L_ankle.sldprt          → AX_L_ANKLE
│   ├── XL330_R_hip_yaw.sldprt        → AX_R_HIP_YAW
│   ├── XL330_R_hip_pitch.sldprt      → AX_R_HIP_PITCH
│   ├── XL330_R_knee.sldprt           → AX_R_KNEE
│   └── XL330_R_ankle.sldprt          → AX_R_ANKLE
│
├── ELECTRONICS (mate to PT_*)
│   ├── pi5.sldprt                    → PT_PI5
│   ├── pca9685.sldprt                → PT_PCA9685
│   ├── battery.sldprt                → PT_BATTERY
│   ├── tp4056.sldprt                 → PT_TP4056
│   └── usb_c_breakout.sldprt         → PT_USB_C
│
├── AUDIO + SENSORS (mate to PT_*)
│   ├── speaker_28mm.sldprt           → PT_SPEAKER
│   ├── max98357a.sldprt              → PT_AMP
│   ├── sph0641_mic.sldprt            → PT_MIC
│   ├── mpu6050.sldprt                → PT_IMU
│   ├── hcsr04_mini.sldprt            → PT_ULTRASONIC
│   ├── led_eye_L.sldprt              → PT_LED_L_EYE
│   ├── led_eye_R.sldprt              → PT_LED_R_EYE
│   └── led_chest.sldprt              → PT_LED_CHEST
│
└── STRUCTURAL FRAME (YOUR DESIGN — mate to SSP)
    ├── frame_base.sldprt
    ├── frame_torso.sldprt
    ├── frame_head.sldprt
    ├── frame_arm_left.sldprt
    ├── frame_arm_right.sldprt
    ├── frame_leg_left.sldprt
    └── frame_leg_right.sldprt
```

---

## Reference Links

- [SolidWorks Skeleton Part Method (Javelin)](https://www.javelin-tech.com/blog/2017/07/solidworks-skeleton-part/)
- [Analyzing Kinematics with Layout Tools (CATI)](https://www.cati.com/blog/solidworks-analyzing-kinematics-with-2d-sketch-layout-tools/)
- [Kinematic & Dynamic Analysis (SolidWorks Blog)](https://blogs.solidworks.com/solidworksblog/2023/03/put-your-studies-in-quick-motion-with-kinematic-and-dynamic-analysis.html)
- [Poppy Humanoid CAD files (GrabCAD)](https://grabcad.com/library/poppy-humanoid-1)
- [Poppy Assembly Guide](https://docs.poppy-project.org/en/assembly-guides/poppy-humanoid/index.html)

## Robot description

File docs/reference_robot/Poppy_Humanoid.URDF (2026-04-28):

<?xml version="1.0" encoding="utf-8"?>
<robot name="Poppy_Humanoid">
	<link name="pelvis">
		<inertial>
			<origin xyz="-0.000134932459328483 -0.000399086261064929 0.00195556930608449" rpy="0 0 0"></origin>
			<mass value="0.18520035953947"></mass>
			<inertia ixx="0.000101804322229161" ixy="3.56589402562651E-08" ixz="-1.38613151054156E-05" iyy="0.000142404075398435" iyz="-3.50682832702007E-06" izz="9.38193247222871E-05"></inertia>
		</inertial>
		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
		<mass>0.18508</mass>
	</link>
	<link name="r_hip">
		<inertial>
			<origin xyz="-0.0419310610774408 0.0190565121211527 -0.0049369159749795" rpy="0 0 0"></origin>
			<mass value="0.0843835237958419"></mass>
			<inertia ixx="2.80785419197495E-05" ixy="-1.23046307113086E-06" ixz="6.6239556232755E-07" iyy="2.83383567782285E-05" iyz="-1.44609279432087E-06" izz="2.15931686710985E-05"></inertia>
		</inertial>
		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
		<mass>0.08433</mass>
	</link>
	<link name="r_hip_motor">
		<inertial>
			<origin xyz="0.00012677211714017 -0.0228896110294103 -0.0134988950219984" rpy="0 0 0"></origin>
			<mass value="0.0831707898707576"></mass>
			<inertia ixx="2.94087635631147E-05" ixy="-1.19904545841814E-08" ixz="-2.40263672865729E-07" iyy="3.59801748266375E-05" iyz="7.9755837503152E-07" izz="2.29200602273928E-05"></inertia>
		</inertial>
		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
		<mass>0.13848</mass>
	</link>
	<link name="r_thigh">
		<inertial>
			<origin xyz="0.0192501209789311 -0.140974172218775 0.000432765258959229" rpy="0 0 0"></origin>
			<mass value="0.116386255838466"></mass>
			<inertia ixx="0.000357762131890894" ixy="-4.71321103204108E-05" ixz="2.18885095933642E-06" iyy="5.14619739065129E-05" iyz="-5.54069244270054E-06" izz="0.000370171570432626"></inertia>
		</inertial>
		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
		<mass>0.12066</mass>
	</link>
	<link name="r_shin">
		<inertial>
			<origin xyz="-0.00150809388022299 -0.137041584549603 0.0228988594303728" rpy="0 0 0"></origin>
			<mass value="0.115582219792398"></mass>
			<inertia ixx="0.000397225397723862" ixy="-1.73262609639968E-05" ixz="1.32921239310872E-08" iyy="3.98086710206889E-05" iyz="-5.89721905441721E-07" izz="0.000393657905933943"></inertia>
		</inertial>
		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
		<mass>0.11169</mass>
	</link>
	<link name="r_foot">
		<inertial>
			<origin xyz="0.0204293303781304 -0.0233359048261193 0.0268526073213802" rpy="0 0 0"></origin>
			<mass value="0.0467879950319091"></mass>
			<inertia ixx="8.14403907813341E-05" ixy="1.79180509533517E-07" ixz="-2.42059026946486E-06" iyy="8.8648252995759E-05" iyz="-3.23018791598496E-06" izz="1.79463752431845E-05"></inertia>
		</inertial>
		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
		<mass>0.04674</mass>
	</link>
	<link name="l_hip">
		<inertial>
			<origin xyz="0.0419306472605077 0.0190563885809745 -0.00493699078761145" rpy="0 0 0"></origin>
			<mass value="0.084384314388701"></mass>
			<inertia ixx="2.80793467645287E-05" ixy="1.23086422338588E-06" ixz="-6.62398430684737E-07" iyy="2.83405782814578E-05" iyz="-1.44600299896268E-06" izz="2.15947433435168E-05"></inertia>
		</inertial>
		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
		<mass>0.08434</mass>
	</link>
	<link name="l_hip_motor">
		<inertial>
			<origin xyz="-0.000127079593402107 -0.0228896103855824 -0.0134988950219984" rpy="0 0 0"></origin>
			<mass value="0.0831707898707576"></mass>
			<inertia ixx="2.94087634441972E-05" ixy="1.14532470512781E-08" ixz="2.40221424306256E-07" iyy="3.59801683348766E-05" iyz="7.97560828147263E-07" izz="2.29200536167144E-05"></inertia>
		</inertial>
		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
		<mass>0.13848</mass>
	</link>
	<link name="l_thigh">
		<inertial>
			<origin xyz="-0.019252460356064 -0.142230931721003 0.000612323159069193" rpy="0 0 0"></origin>
			<mass value="0.114854459344049"></mass>
			<inertia ixx="0.000344974307251891" ixy="4.73949176309948E-05" ixz="-2.2011322605997E-06" iyy="5.11655383215627E-05" iyz="-3.3911468808746E-06" izz="0.000357718491831138"></inertia>
		</inertial>
		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
		<mass>0.12152</mass>
	</link>
	<link name="l_shin">
		<inertial>
			<origin xyz="-0.00150809145543363 -0.137041584769234 -0.0229033576380381" rpy="0 0 0"></origin>
			<mass value="0.11558221959692"></mass>
			<inertia ixx="0.000397225344473892" ixy="-1.7326274763791E-05" ixz="-3.52146929156471E-09" iyy="3.98086215785412E-05" iyz="5.50111227416849E-07" izz="0.000393657903677591"></inertia>
		</inertial>
		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
		<mass>0.11169</mass>
	</link>
	<link name="l_foot">
		<inertial>
			<origin xyz="-0.020427799658059 -0.023322293418243 0.0268332758297585" rpy="0 0 0"></origin>
			<mass value="0.0468257348098641"></mass>
			<inertia ixx="8.1463512692765E-05" ixy="-1.79215713282762E-07" ixz="2.42595321155028E-06" iyy="8.8658680494918E-05" iyz="-3.23538234039819E-06" izz="1.7963767676241E-05"></inertia>
		</inertial>
		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
		<mass>0.04678</mass>
	</link>
	<link name="abs_motors">
		<inertial>
			<origin xyz="-6.29779489192246E-05 0.0133591399673186 -0.0195687625589375" rpy="0 0 0"></origin>
			<mass value="0.16766708386429"></mass>
			<inertia ixx="0.000151720676825684" ixy="-2.41666285846992E-07" ixz="-2.06688911297549E-07" iyy="0.000131382009077746" iyz="-2.13904639264389E-06" izz="6.52732386194484E-05"></inertia>
		</inertial>
		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
		<mass>0.27838</mass>
	</link>
	<link name="abdomen">
		<inertial>
			<origin xyz="4.70358640929572E-07 0.0445314260459549 -0.022296044885406" rpy="0 0 0"></origin>
			<mass value="0.0384110457457536"></mass>
			<inertia ixx="5.9365236572053E-05" ixy="-8.257716306361E-11" ixz="-2.55036869156096E-10" iyy="5.98640694082658E-05" iyz="3.94818292640265E-07" izz="2.35987614893539E-05"></inertia>
		</inertial>
		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
		<mass>0.03839</mass>
	</link>
	<link name="spine">
		<inertial>
			<origin xyz="-2.40411891850495E-07 0.0288451667347867 -0.0100975118547382" rpy="0 0 0"></origin>
			<mass value="0.0926815106655512"></mass>
			<inertia ixx="3.84763910015325E-05" ixy="-1.20593001730888E-09" ixz="-2.38589260905183E-10" iyy="2.7320514654861E-05" iyz="1.47490149318973E-06" izz="3.26595211965373E-05"></inertia>
		</inertial>
		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
		<mass>0.09264</mass>
	</link>
	<link name="bust_motors">
		<inertial>
			<origin xyz="3.50872416629779E-05 0.0105220286877652 -0.0174331453843439" rpy="0 0 0"></origin>
			<mass value="0.158876054570625"></mass>
			<inertia ixx="0.000100953683249293" ixy="-3.89105307189684E-07" ixz="9.71749941401585E-08" iyy="8.94288410563621E-05" iyz="-1.31738255727689E-06" izz="4.26225972692235E-05"></inertia>
		</inertial>
		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
		<mass>0.15889</mass>
	</link>
	<link name="chest">
		<inertial>
			<origin xyz="2.35256459143538E-06 0.0514948183080913 -0.0105463056982622" rpy="0 0 0"></origin>
			<mass value="0.262925523172723"></mass>
			<inertia ixx="0.000154597294293882" ixy="2.32304239504647E-08" ixz="-2.47140128362103E-08" iyy="0.000750952782458072" iyz="1.53530143139102E-06" izz="0.000688549998744818"></inertia>
		</inertial>
		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
		<mass>0.27528</mass>
	</link>
	<link name="neck">
		<inertial>
			<origin xyz="-0.00147486363077957 0.00928455262636602 2.89600749219313E-06" rpy="0 0 0"></origin>
			<mass value="0.00588496516988365"></mass>
			<inertia ixx="7.25596636570396E-07" ixy="-9.29944216419538E-08" ixz="2.01438227027406E-10" iyy="2.33535976458607E-06" iyz="1.55383710797264E-11" izz="2.57395421284165E-06"></inertia>
		</inertial>
		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
		<mass>0.00588</mass>
	</link>
	<link name="head">
		<inertial>
			<origin xyz="0.000557544173188459 0.0327437693305889 -0.0132545775103434" rpy="0 0 0"></origin>
			<mass value="0.188564323997503"></mass>
			<inertia ixx="0.000353329921483274" ixy="-2.17595216032547E-07" ixz="4.10678991843685E-06" iyy="0.000384587155295662" iyz="-2.16656424152966E-05" izz="0.000396626339401006"></inertia>
		</inertial>
		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
		<mass>0.2126</mass>
	</link>
	<link name="l_shoulder">
		<inertial>
			<origin xyz="0.0105246491971973 0.00179805316216127 -0.00915201992957032" rpy="0 0 0"></origin>
			<mass value="0.00843598968780806"></mass>
			<inertia ixx="3.39606863056539E-06" ixy="-4.79545875245114E-08" ixz="2.95435354929514E-08" iyy="3.56726082486902E-06" iyz="1.00382310579659E-08" izz="1.84634806401887E-06"></inertia>
		</inertial>
		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
		<mass>0.00838</mass>
	</link>
	<link name="l_shoulder_motor">
		<inertial>
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

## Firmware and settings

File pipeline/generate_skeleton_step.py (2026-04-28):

"""
Generate HawaBot Spark skeleton as a high-fidelity STEP file.

Produces a single-body frame with:
- Proper servo-shaped pockets (body + tab slots + turret clearance + shaft holes)
- Screw bosses at all servo mounting points
- 40 magnet pockets (⌀6.1 × 3.1mm) at predefined positions
- Wire channels (vertical + horizontal)
- Pi Pico W pocket with USB access slot and mounting standoffs

Coordinate system: Z-up, origin at center of base plate top surface.
Target height: 200mm.
"""

import cadquery as cq
import os
import math

# ── Global Parameters ─────────────────────────────────────────────────────

C_wall = 0.3        # Servo-to-pocket clearance per side
T_wall = 2.5        # Minimum structural wall
D_wire = 6.0        # Wire channel diameter
D_screw = 2.0       # M2 screw pilot hole diameter
SCREW_BOSS_OD = 5.0 # Screw boss outer diameter

# Base plate
BASE_W = 90.0
BASE_D = 70.0
BASE_H = 20.0
BASE_R = 6.0

# Torso
TORSO_D = 24.0       # Cross-section diameter / side length
TORSO_R = 4.0        # Corner radius for rounded-rect cross-section

# Servo positions
WAIST_Z = 10.0
SHOULDER_Z = 110.0
SHOULDER_X = 40.0
HEAD_PAN_Z = 120.0
HEAD_TILT_Z = 148.0

# SG90 servo dimensions
SG90_L = 22.7       # Body length (front-back)
SG90_W = 12.2       # Body width (side-side)
SG90_H = 27.0       # Body height (bottom to case top)
SG90_H_total = 32.3 # Bottom to spline top
SG90_tab_L = 32.3   # Tab-to-tab length
SG90_tab_T = 2.8    # Tab thickness
SG90_tab_Z = 17.0   # Tab underside height from servo bottom
SG90_turret_D = 11.8
SG90_turret_H = 5.96
SG90_shaft_offset = 6.2
SG90_spline_OD = 4.8
SG90_hole_D = 2.0
SG90_hole_inset = 2.0

# SG90 cavity (body + clearance)
SG90_cav_L = SG90_L + 2 * C_wall
SG90_cav_W = SG90_W + 2 * C_wall
SG90_cav_H = SG90_H + 2 * C_wall

# MG90S servo dimensions
MG90S_L = 22.8
MG90S_W = 12.4
MG90S_H = 28.4
MG90S_H_total = 32.5
MG90S_tab_L = 32.1
MG90S_tab_T = 2.8
MG90S_tab_Z = 18.5
MG90S_spline_OD = 4.8
MG90S_hole_D = 2.0

# MG90S cavity
MG90S_cav_L = MG90S_L + 2 * C_wall
MG90S_cav_W = MG90S_W + 2 * C_wall
MG90S_cav_H = MG90S_H + 2 * C_wall

# Pi Pico W
PICO_L = 51.0
PICO_W = 21.0
PICO_H = 12.0
PICO_cavity_L = PICO_L + 6    # 57
PICO_cavity_W = PICO_W + 4    # 25
PICO_X_OFFSET = 25.0
PICO_hole_L = 47.0            # Mounting hole spacing (length)
PICO_hole_W = 11.4            # Mounting hole spacing (width)
PICO_hole_D = 2.1
PICO_standoff_H = 5.0         # Standoff height
PICO_standoff_OD = 4.5        # Standoff outer diameter

# Magnets
MAG_POCKET_D = 6.1
MAG_POCKET_H = 3.1
MAG_BOSS_OD = 10.0   # Only used on shells, not skeleton

# ── Magnet Positions ──────────────────────────────────────────────────────
# Each tuple: (x, y, z, face_normal_x, face_normal_y, face_normal_z)
# The normal indicates which direction to cut the pocket into the surface.

HEAD_MAGNETS = [
    (0, -14, 125, 0, -1, 0),    # H1 Front
    (0, 14, 125, 0, 1, 0),      # H2 Back
    (-14, 0, 125, -1, 0, 0),    # H3 Left
    (14, 0, 125, 1, 0, 0),      # H4 Right
    (-10, -10, 125, -1, -1, 0), # H5 Front-Left
    (10, -10, 125, 1, -1, 0),   # H6 Front-Right
    (-10, 10, 125, -1, 1, 0),   # H7 Back-Left
    (10, 10, 125, 1, 1, 0),     # H8 Back-Right
]

TORSO_MAGNETS = [
    # Z=30 ring
    (0, -14, 30, 0, -1, 0),     # T1
    (0, 14, 30, 0, 1, 0),       # T2
    (-14, 0, 30, -1, 0, 0),     # T7
    (14, 0, 30, 1, 0, 0),       # T8
    # Z=70 ring
    (0, -14, 70, 0, -1, 0),     # T3
    (0, 14, 70, 0, 1, 0),       # T4
    (-14, 0, 70, -1, 0, 0),     # T9
    (14, 0, 70, 1, 0, 0),       # T10
    # Z=100 ring
    (0, -14, 100, 0, -1, 0),    # T5
    (0, 14, 100, 0, 1, 0),      # T6
    (-14, 0, 100, -1, 0, 0),    # T11
    (14, 0, 100, 1, 0, 0),      # T12
]

LEFT_ARM_MAGNETS = [
    (-40, -10, 110, 0, -1, 0),  # LA1 Front
    (-40, 10, 110, 0, 1, 0),    # LA2 Back
    (-40, 0, 100, 0, 0, -1),    # LA3 Bottom
    (-40, 0, 120, 0, 0, 1),     # LA4 Top
    (-52, -8, 110, -1, 0, 0),   # LA5 Outer front
    (-52, 8, 110, -1, 0, 0),    # LA6 Outer back
]

RIGHT_ARM_MAGNETS = [
    (40, -10, 110, 0, -1, 0),   # RA1
    (40, 10, 110, 0, 1, 0),     # RA2
    (40, 0, 100, 0, 0, -1),     # RA3
    (40, 0, 120, 0, 0, 1),      # RA4
    (52, -8, 110, 1, 0, 0),     # RA5
    (52, 8, 110, 1, 0, 0),      # RA6
]

BASE_MAGNETS = [
    (-35, -28, -10, 0, -1, 0),  # B1 Front-left
    (35, -28, -10, 0, -1, 0),   # B2 Front-right
    (-35, 28, -10, 0, 1, 0),    # B3 Back-left
    (35, 28, -10, 0, 1, 0),     # B4 Back-right
    (0, -28, -10, 0, -1, 0),    # B5 Front-center
    (0, 28, -10, 0, 1, 0),      # B6 Back-center
    (-40, 0, -10, -1, 0, 0),    # B7 Left-center
    (40, 0, -10, 1, 0, 0),      # B8 Right-center
]


# ── Helper Functions ──────────────────────────────────────────────────────

def _sg90_pocket(workplane, x, y, z, shaft_axis="Z"):
    """
    Cut an SG90 servo pocket into a solid.
    shaft_axis: "Z" (shaft up), "Y" (shaft forward), "X" (shaft sideways)

    Cuts: body cavity + tab slot + turret clearance + shaft hole.
    Returns the workplane with cuts applied.
    """
    wp = workplane

    if shaft_axis == "Z":
        # Servo body pocket: centered at (x, y), bottom at z
        body = (
            cq.Workplane("XY")
            .workplane(offset=z + SG90_cav_H / 2)
            .center(x, y)
            .rect(SG90_cav_L, SG90_cav_W)
            .extrude(SG90_cav_H / 2, both=True)
        )
        wp = wp.cut(body)

        # Tab slot: wider, at tab height
        tab_z = z + SG90_tab_Z
        tab = (
            cq.Workplane("XY")
            .workplane(offset=tab_z + (SG90_tab_T + 2 * C_wall) / 2)
            .center(x, y)
            .rect(SG90_tab_L + 2 * C_wall, SG90_cav_W)
            .extrude((SG90_tab_T + 2 * C_wall) / 2, both=True)
        )
        wp = wp.cut(tab)

        # Turret clearance above body
        turret_bottom = z + SG90_cav_H
        turret_h = SG90_turret_H + 2 * C_wall
        turret = (
            cq.Workplane("XY")
            .workplane(offset=turret_bottom)
            .center(x, y)
            .circle((SG90_turret_D + 2 * C_wall) / 2)
            .extrude(turret_h)
        )
        wp = wp.cut(turret)

        # Shaft hole above turret
        shaft_bottom = turret_bottom + turret_h
        shaft_clearance_h = 10  # Extra space for horn rotation
        shaft = (
            cq.Workplane("XY")
            .workplane(offset=shaft_bottom)
            .center(x, y)
            .circle((SG90_spline_OD + 4) / 2)  # Horn clearance
            .extrude(shaft_clearance_h)
        )
        wp = wp.cut(shaft)

    elif shaft_axis == "Y":
        # Rotated 90°: servo body L along X, servo body W along Z,
        # servo body H along Y. Shaft points +Y.
        body = (
            cq.Workplane("XZ")
            .workplane(offset=y)
            .center(x, z)
            .rect(SG90_cav_W, SG90_cav_L)  # W along X, L along Z (in XZ plane)
            .extrude(SG90_cav_H / 2, both=True)
        )
        wp = wp.cut(body)

        # Tab slot (wider along the long axis, which is now Z)
        tab_offset_y = y + SG90_tab_Z - SG90_H / 2
        tab = (
            cq.Workplane("XZ")
            .workplane(offset=tab_offset_y)
            .center(x, z)
            .rect(SG90_cav_W, SG90_tab_L + 2 * C_wall)
            .extrude((SG90_tab_T + 2 * C_wall) / 2, both=True)
        )
        wp = wp.cut(tab)

        # Turret clearance (extends in +Y)
        turret_y = y + SG90_cav_H / 2
        turret = (
            cq.Workplane("XZ")
            .workplane(offset=turret_y)
            .center(x, z)
            .circle((SG90_turret_D + 2 * C_wall) / 2)
            .extrude(SG90_turret_H + 2 * C_wall)
        )
        wp = wp.cut(turret)

        # Shaft hole (+Y direction)
        shaft_y = turret_y + SG90_turret_H + 2 * C_wall
        shaft = (
            cq.Workplane("XZ")
            .workplane(offset=shaft_y)
            .center(x, z)
            .circle((SG90_spline_OD + 4) / 2)
            .extrude(10)
        )
        wp = wp.cut(shaft)

    return wp


def _mg90s_pocket(workplane, x, y, z, shaft_axis="X", shaft_sign=-1):
    """
    Cut an MG90S servo pocket for shoulder mount.
    Servo oriented with shaft pointing along X axis (outward from body).
    shaft_sign: -1 for left (shaft -X), +1 for right (shaft +X).

    Servo body H dimension runs along X (the shaft axis).
    Servo body L dimension runs along Y.
    Servo body W dimension runs along Z.
    """
    wp = workplane

    # Body pocket centered at (x, y, z)
    body = (
        cq.Workplane("YZ")
        .workplane(offset=x)
        .center(y, z)
        .rect(MG90S_cav_L, MG90S_cav_W)
        .extrude(MG90S_cav_H / 2, both=True)
    )
    wp = wp.cut(body)

    # Tab slot: extends wider along Y at tab height
    # Tab Z position relative to servo bottom: MG90S_tab_Z
    # Servo bottom is at x - shaft_sign * MG90S_cav_H/2 (opposite side from shaft)
    tab_x = x  # Tabs are at a fixed height up the servo body
    tab = (
        cq.Workplane("YZ")
        .workplane(offset=tab_x)
        .center(y, z)
        .rect(MG90S_tab_L + 2 * C_wall, MG90S_cav_W)
        .extrude((MG90S_tab_T + 2 * C_wall) / 2, both=True)
    )
    wp = wp.cut(tab)

    # Shaft hole: extends outward from servo in shaft direction
    shaft_start_x = x + shaft_sign * MG90S_cav_H / 2
    shaft = (
        cq.Workplane("YZ")
        .workplane(offset=shaft_start_x)
        .center(y, z)
        .circle((MG90S_spline_OD + 4) / 2)
        .extrude(shaft_sign * 20)  # Through the bracket and out
    )
    wp = wp.cut(shaft)

    return wp


def _screw_holes_sg90(workplane, x, y, z, shaft_axis="Z"):
    """Add M2 screw pilot holes at SG90 tab mounting positions."""
    wp = workplane

    if shaft_axis == "Z":
        # Tab holes are along the long axis (X direction), at tab height
        tab_z = z + SG90_tab_Z
        # 4 holes: 2 on each tab end
        # Tab extends ±SG90_tab_L/2 from center along X
        # Holes are inset from tab edge by SG90_hole_inset
        hole_x_offset = SG90_tab_L / 2 - SG90_hole_inset
        for dx_sign in [-1, 1]:
            for dy_sign in [-1, 1]:
                hx = x + dx_sign * hole_x_offset
                hy = y + dy_sign * (SG90_W / 2 - 1)  # Near tab edges
                hole = (
                    cq.Workplane("XY")
                    .workplane(offset=tab_z - 4)
                    .center(hx, hy)
                    .circle(D_screw / 2)
                    .extrude(8)
                )
                wp = wp.cut(hole)
    elif shaft_axis == "Y":
        tab_offset_y = y + SG90_tab_Z - SG90_H / 2
        hole_z_offset = SG90_tab_L / 2 - SG90_hole_inset
        for dz_sign in [-1, 1]:
            for dx_sign in [-1, 1]:
                hz = z + dz_sign * hole_z_offset
                hx = x + dx_sign * (SG90_W / 2 - 1)
                hole = (
                    cq.Workplane("XZ")
                    .workplane(offset=tab_offset_y - 4)
                    .center(hx, hz)
                    .circle(D_screw / 2)
                    .extrude(8)
                )
                wp = wp.cut(hole)

    return wp


def _screw_holes_mg90s(workplane, x, y, z, shaft_sign=-1):
    """Add M2 screw pilot holes at MG90S tab mounting positions."""
    wp = workplane

    hole_y_offset = MG90S_tab_L / 2 - 2.0  # Inset from tab edge
    for dy_sign in [-1, 1]:
        for dz_sign in [-1, 1]:
            hy = y + dy_sign * hole_y_offset
            hz = z + dz_sign * (MG90S_W / 2 - 1)
            hole = (
                cq.Workplane("YZ")
                .workplane(offset=x - 4)
                .center(hy, hz)
                .circle(D_screw / 2)
                .extrude(8)
            )
            wp = wp.cut(hole)

    return wp


def _cut_magnet_pockets(workplane, magnet_list):
    """Cut magnet pockets into the solid at each position."""
    wp = workplane

    for mx, my, mz, nx, ny, nz in magnet_list:
        # Normalize the normal vector
        length = math.sqrt(nx * nx + ny * ny + nz * nz)
        if length == 0:
            continue
        nx, ny, nz = nx / length, ny / length, nz / length

        # Determine which workplane to use based on dominant normal direction
        if abs(nz) > abs(nx) and abs(nz) > abs(ny):
            # Normal is mostly Z — cut from top or bottom face
            direction = 1 if nz > 0 else -1
            pocket = (
                cq.Workplane("XY")
                .workplane(offset=mz)
                .center(mx, my)
                .circle(MAG_POCKET_D / 2)
                .extrude(direction * MAG_POCKET_H)
            )
        elif abs(ny) > abs(nx):
            # Normal is mostly Y — cut from front or back face
            direction = 1 if ny > 0 else -1
            pocket = (
                cq.Workplane("XZ")
                .workplane(offset=my)
                .center(mx, mz)
                .circle(MAG_POCKET_D / 2)
                .extrude(direction * MAG_POCKET_H)
            )
        else:
            # Normal is mostly X — cut from left or right face
            direction = 1 if nx > 0 else -1
            pocket = (
                cq.Workplane("YZ")
                .workplane(offset=mx)
                .center(my, mz)
                .circle(MAG_POCKET_D / 2)
                .extrude(direction * MAG_POCKET_H)
            )

        wp = wp.cut(pocket)

    return wp


# ── Main Build ────────────────────────────────────────────────────────────

def build_skeleton_frame():
    """
    Build the complete skeleton frame as a single solid body.
    This is the 3D-printed structural part — everything mounts to this.
    """

    # ── 1. Base Plate ─────────────────────────────────────────────────────
    # Z = -BASE_H to Z = 0
    frame = (
        cq.Workplane("XY")
        .workplane(offset=-BASE_H / 2)
        .rect(BASE_W, BASE_D)
        .extrude(BASE_H / 2, both=True)
    )
    frame = frame.edges("|Z and (not >Z)").fillet(BASE_R)

    # ── 2. Waist Servo Column ─────────────────────────────────────────────
    # Solid block rising from base surface to house the waist servo
    # Outer dimensions: servo + walls on each side
    waist_outer_l = SG90_tab_L + 2 * C_wall + 2 * T_wall  # ~37.3mm
    waist_outer_w = SG90_cav_W + 2 * T_wall                # ~17.8mm
    waist_outer_h = SG90_cav_H + SG90_turret_H + 4         # ~37.6mm

    waist_block = (
        cq.Workplane("XY")
        .workplane(offset=waist_outer_h / 2)
        .rect(waist_outer_l, waist_outer_w)
        .extrude(waist_outer_h / 2, both=True)
    )
    frame = frame.union(waist_block)

    # ── 3. Torso Column ──────────────────────────────────────────────────
    # Rounded rectangle from Z=0 up to HEAD_PAN_Z
    torso = (
        cq.Workplane("XY")
        .workplane(offset=0)
        .rect(TORSO_D, TORSO_D)
        .extrude(HEAD_PAN_Z)
    )
    # Round the vertical edges
    torso = torso.edges("|Z").fillet(TORSO_R)
    frame = frame.union(torso)

    # ── 4. Shoulder Brackets ──────────────────────────────────────────────
    # Each bracket extends from torso column out to the shoulder position
    bracket_depth = MG90S_cav_L + 2 * T_wall    # Y dimension (~28.4mm)
    bracket_height = MG90S_cav_W + 2 * T_wall   # Z dimension (~17.4mm)

    for sign in [-1, 1]:  # -1 = left, +1 = right
        # Bracket extends from torso edge to shoulder position + some overhang
        inner_x = sign * (TORSO_D / 2 - 2)  # Start 2mm inside torso for overlap
        outer_x = sign * (SHOULDER_X + 15)   # Extend 15mm past servo center
        mid_x = (inner_x + outer_x) / 2
        width = abs(outer_x - inner_x)

        bracket = (
            cq.Workplane("XY")
            .workplane(offset=SHOULDER_Z)
            .center(mid_x, 0)
            .rect(width, bracket_depth)
            .extrude(bracket_height / 2, both=True)
        )
        # Round the ends
        bracket = bracket.edges("|X").fillet(min(2.0, bracket_height / 4))
        frame = frame.union(bracket)

    # ── 5. Head Pan Mount ─────────────────────────────────────────────────
    # Platform at top of torso for pan servo
    pan_mount_l = SG90_tab_L + 2 * C_wall + 2 * T_wall
    pan_mount_w = SG90_cav_W + 2 * T_wall
    pan_mount_h = SG90_cav_H + SG90_turret_H + 4

    pan_mount = (
        cq.Workplane("XY")
        .workplane(offset=HEAD_PAN_Z)
        .rect(pan_mount_l, pan_mount_w)
        .extrude(pan_mount_h)
    )
    frame = frame.union(pan_mount)

    # ── 6. Head Tilt Mount ────────────────────────────────────────────────
    # Bracket above pan servo for tilt servo (rotated 90°: shaft → +Y)
    # Tilt servo body: W along X, L along Z, H along Y
    tilt_mount_x = SG90_cav_W + 2 * T_wall   # ~17.8mm (X)
    tilt_mount_z = SG90_cav_L + 2 * T_wall   # ~28.3mm (Z)
    tilt_mount_y = SG90_cav_H + 2 * T_wall   # ~32.6mm (Y)

    tilt_mount = (
        cq.Workplane("XY")
        .workplane(offset=HEAD_TILT_Z)
        .rect(tilt_mount_x, tilt_mount_y)
        .extrude(tilt_mount_z / 2, both=True)
    )
    frame = frame.union(tilt_mount)

    # Connecting bridge from pan mount top to tilt mount
    bridge_bottom = HEAD_PAN_Z + pan_mount_h
    bridge_top = HEAD_TILT_Z - tilt_mount_z / 2
    if bridge_top > bridge_bottom:
        bridge = (
            cq.Workplane("XY")
            .workplane(offset=bridge_bottom)
            .rect(min(pan_mount_l, tilt_mount_x), min(pan_mount_w, tilt_mount_y))
            .extrude(bridge_top - bridge_bottom)
        )
        frame = frame.union(bridge)

    # ── 7. Head Magnet Ring ───────────────────────────────────────────────
    # Cylindrical ring around the neck area for head shell magnets to grab
    ring_r = 16.0   # Outer radius of the ring
    ring_h = 8.0    # Height of the ring
    ring_z = 122.0  # Just above pan servo
    ring = (
        cq.Workplane("XY")
        .workplane(offset=ring_z)
        .circle(ring_r)
        .extrude(ring_h)
    )
    frame = frame.union(ring)

    # ══════════════════════════════════════════════════════════════════════
    # CUT OPERATIONS — servo pockets, wire channels, magnet pockets, etc.
    # ══════════════════════════════════════════════════════════════════════

    # ── 8. Waist Servo Pocket ─────────────────────────────────────────────
    frame = _sg90_pocket(frame, 0, 0, WAIST_Z - C_wall, shaft_axis="Z")
    frame = _screw_holes_sg90(frame, 0, 0, WAIST_Z - C_wall, shaft_axis="Z")

    # Cable exit slot on the side of waist column
    cable_exit = (
        cq.Workplane("XZ")
        .workplane(offset=-waist_outer_w / 2 - 1)
        .center(waist_outer_l / 2 - 3, WAIST_Z + 5)
        .rect(6, 4)
        .extrude(waist_outer_w + 2)
    )
    frame = frame.cut(cable_exit)

    # ── 9. Shoulder Servo Pockets ─────────────────────────────────────────
    # Left shoulder: shaft points -X
    frame = _mg90s_pocket(frame, -SHOULDER_X, 0, SHOULDER_Z,
                          shaft_axis="X", shaft_sign=-1)
    frame = _screw_holes_mg90s(frame, -SHOULDER_X, 0, SHOULDER_Z, shaft_sign=-1)

    # Right shoulder: shaft points +X
    frame = _mg90s_pocket(frame, SHOULDER_X, 0, SHOULDER_Z,
                          shaft_axis="X", shaft_sign=1)
    frame = _screw_holes_mg90s(frame, SHOULDER_X, 0, SHOULDER_Z, shaft_sign=1)

    # ── 10. Head Pan Servo Pocket ─────────────────────────────────────────
    frame = _sg90_pocket(frame, 0, 0, HEAD_PAN_Z, shaft_axis="Z")
    frame = _screw_holes_sg90(frame, 0, 0, HEAD_PAN_Z, shaft_axis="Z")

    # ── 11. Head Tilt Servo Pocket ────────────────────────────────────────
    frame = _sg90_pocket(frame, 0, 0, HEAD_TILT_Z, shaft_axis="Y")
    frame = _screw_holes_sg90(frame, 0, 0, HEAD_TILT_Z, shaft_axis="Y")

    # ── 12. Pi Pico W Pocket ──────────────────────────────────────────────
    # Cut from bottom face of base plate, centered at X=PICO_X_OFFSET
    pico_pocket = (
        cq.Workplane("XY")
        .workplane(offset=-BASE_H + PICO_H / 2)
        .center(PICO_X_OFFSET, 0)
        .rect(PICO_cavity_L, PICO_cavity_W)
        .extrude(PICO_H / 2, both=True)
    )
    frame = frame.cut(pico_pocket)

    # USB access slot: from Pico pocket right edge to base +X edge
    usb_slot_w = 14.0
    pico_right_edge = PICO_X_OFFSET + PICO_cavity_L / 2
    base_right_edge = BASE_W / 2
    usb_slot_l = base_right_edge - pico_right_edge + 2  # +2 to punch through
    usb_slot = (
        cq.Workplane("XY")
        .workplane(offset=-BASE_H + PICO_H / 2)
        .center(pico_right_edge + usb_slot_l / 2 - 1, 0)
        .rect(usb_slot_l, usb_slot_w)
        .extrude(PICO_H / 2, both=True)
    )
    frame = frame.cut(usb_slot)

    # Pico mounting standoffs (4 posts rising from pocket floor)
    for dx_sign in [-1, 1]:
        for dy_sign in [-1, 1]:
            sx = PICO_X_OFFSET + dx_sign * PICO_hole_L / 2
            sy = dy_sign * PICO_hole_W / 2
            standoff = (
                cq.Workplane("XY")
                .workplane(offset=-BASE_H)
                .center(sx, sy)
                .circle(PICO_standoff_OD / 2)
                .extrude(PICO_standoff_H)
            )
            frame = frame.union(standoff)

            # Pilot hole through standoff
            pilot = (
                cq.Workplane("XY")
                .workplane(offset=-BASE_H)
                .center(sx, sy)
                .circle(PICO_hole_D / 2)
                .extrude(PICO_standoff_H + 1)
            )
            frame = frame.cut(pilot)

    # ── 13. Wire Channels ─────────────────────────────────────────────────
    # Vertical: through torso column, offset from center
    wire_x = TORSO_D / 2 - D_wire / 2 - 1  # Near the surface but inside
    vert_wire = (
        cq.Workplane("XY")
        .workplane(offset=-BASE_H)
        .center(wire_x, 0)
        .circle(D_wire / 2)
        .extrude(BASE_H + HEAD_PAN_Z + 5)
    )
    frame = frame.cut(vert_wire)
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

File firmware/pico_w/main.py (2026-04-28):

"""HawaBot Pico W firmware — MicroPython servo controller.

Flash this onto the Raspberry Pi Pico W.  It listens for simple text
commands on USB serial (115200 baud) and drives hobby servos via PWM.

Wiring (default — matches PicoDriver.DEFAULT_PIN_MAP):
  GP0 → waist_yaw servo signal
  GP1 → left_shoulder_pitch servo signal
  GP2 → right_shoulder_pitch servo signal
  GP3 → head_pan servo signal
  GP4 → head_tilt servo signal
  VSYS (pin 39) → optional voltage divider to GP26 (ADC0) for battery monitoring

Protocol (newline-terminated, 115200 baud):
  S <pin> <pulse_us>   →  OK          Set servo PWM pulse width
  V                     →  V <float>   Read VSYS voltage (or V NONE)
  P                     →  PONG        Ping / health check

Upload:
  1. Install MicroPython on Pico W (hold BOOTSEL, drag .uf2)
  2. Copy this file as main.py to the Pico W filesystem
     (e.g. via Thonny, mpremote, or rshell)
  3. Power-cycle — the Pico will start listening immediately.
"""

import sys
import time
from machine import ADC, PWM, Pin

# ---------------------------------------------------------------------------
# Configuration
# ---------------------------------------------------------------------------

SERVO_PINS = [0, 1, 2, 3, 4]  # GPIO numbers that may drive servos
PWM_FREQ = 50                  # Standard servo PWM frequency (50 Hz)

# Voltage divider on GP26 (ADC0) to monitor VSYS.
# With a 100k/100k divider: V_actual = ADC_voltage * 2
# Set to None to disable voltage monitoring.
VSYS_ADC_PIN = 26
VSYS_DIVIDER_RATIO = 2.0

# ---------------------------------------------------------------------------
# Initialisation
# ---------------------------------------------------------------------------

# Pre-create PWM objects for each allowed pin.
# Servos only start receiving pulses once the first S command is sent.
servos: dict[int, PWM] = {}
for pin_num in SERVO_PINS:
    pwm = PWM(Pin(pin_num))
    pwm.freq(PWM_FREQ)
    pwm.duty_ns(0)  # Off until commanded
    servos[pin_num] = pwm

# Optional voltage ADC.
vsys_adc: ADC | None = None
if VSYS_ADC_PIN is not None:
    vsys_adc = ADC(Pin(VSYS_ADC_PIN))


def set_servo_us(pin: int, pulse_us: int) -> bool:
    """Set a servo's pulse width in microseconds."""
    pwm = servos.get(pin)
    if pwm is None:
        return False
    # Clamp to safe servo range.
    pulse_us = max(500, min(2500, pulse_us))
    pwm.duty_ns(pulse_us * 1000)
    return True


def read_voltage() -> float | None:
    """Read supply voltage via ADC, or None if not wired."""
    if vsys_adc is None:
        return None
    # MicroPython ADC returns 0-65535 for 0-3.3V.
    raw = vsys_adc.read_u16()
    adc_voltage = (raw / 65535) * 3.3
    return round(adc_voltage * VSYS_DIVIDER_RATIO, 2)


# ---------------------------------------------------------------------------
# Main loop — read commands from USB serial, respond
# ---------------------------------------------------------------------------

def main() -> None:
    # Signal that firmware is ready.
    print("HAWABOT PICO READY")

    while True:
        try:
            line = sys.stdin.readline()
        except Exception:
            time.sleep_ms(10)
            continue

        if not line:
            time.sleep_ms(10)
            continue

        line = line.strip()
        if not line:
            continue

        parts = line.split()
        cmd = parts[0]

        if cmd == "P":
            print("PONG")

        elif cmd == "S" and len(parts) == 3:
            try:
                pin = int(parts[1])
                pulse_us = int(parts[2])
            except ValueError:
                print("ERR BAD_ARGS")
                continue
            if set_servo_us(pin, pulse_us):
                print("OK")
            else:
                print("ERR BAD_PIN")

        elif cmd == "V":
            v = read_voltage()
            if v is not None:
                print(f"V {v}")
            else:
                print("V NONE")

        else:
            print("ERR UNKNOWN_CMD")


main()

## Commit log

2026-04-28 HawaBot platform — SDK, shell pipeline, and design platform prototype
    Complete foundation for an educational physical AI robotics platform:
    - SDK: Robot control API with character profiles, 3-tier hardware abstraction
    (Spark tabletop / Core enhanced / Pro bipedal), mock simulation, teach-by-demo
    - Shell pipeline: AI-generated sculpture → skeleton subtract → joint clearance
    cuts → split into printable sections. Proven on real Meshy-generated meshes.
    - Design platform: Flask + Three.js web app with interactive 3D preview,
    tier/plan selection, Meshy API integration (mock and real)
    - Reference: Full-scale Hawabot specs (Poppy-based, 20 DOF) for deriving
    joint limits and curricul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
    [Poppy_Humanoid.URDF, servo_mapping.json]
2026-04-28 Add parametric skeleton spec for SolidWorks CAD design
    Full dimensional reference for building the Spark skeleton in SolidWorks:
    - Exact SG90, MG90S, Pi Pico W dimensions with CAD variable names
    - Assembly layout with parametric coordinates
    - Section boundary rules for multi-body export (5 STLs)
    - Joint rotation clearance definitions
    - Scaling guide for Core and Pro tiers
2026-04-28 Add step-by-step SolidWorks workflow to skeleton spec
    10-step guide from creating the part and setting up global variables
    through building each section body, verifying the assembly, exporting
    STLs, and testing in the pipeline. Includes exact sketch sequences,
    extrude directions, and critical settings (Merge result UNCHECKED).
2026-04-28 Add importable SolidWorks parameter files
    Two formats for importing skeleton dimensions into SolidWorks:
    - equations.txt: direct import via Tools → Equations → Import
    - HawaBot_Spark_Skeleton_Parameters.xlsx: 3-sheet workbook
    (Global Variables, Section Boundaries, Joint Clearances)
    — link as a Design Table or use as reference
    All servo dims, positions, clearances, and computed cavity sizes
    included with CAD variable names ready to use.
    [HawaBot_Spark_Skeleton_Parameters.xlsx]
2026-04-28 Update tiers (voice is Core+, not Spark) and expand skeleton spec
    - Spark: buzzer only, no mic/speaker (AI tutor runs on laptop)
    - Core: mic + speaker for on-robot voice AI
    - Pro: mic array + HQ speaker for full conversational AI
    Excel workbook now has 7 sheets:
    - Global Variables, Section Boundaries, Joint Clearances (existing)
    - Scaling Constraints (min/max for all parametric dimensions)
    - Attachment Features (snap-fit clips, magnet recesses per section)
    - Tier Upgrade Map (what stays/changes across Spark→Core→Pro)
    - Magnet Spec (6×2mm N35 neodymium, recess dimensions, quantities)
    [HawaBot_Spark_Skeleton_Parameters.xlsx]
2026-04-28 Reorganize project structure and add full documentation suite
    Folder cleanup:
    - Move reference robot specs to docs/reference_robot/
    - Move research materials (slides, papers) to docs/research/
    - Remove generated STLs, PNGs, egg-info from root
    - Update all internal references to new paths
    - Clean README with full project structure map
    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
    [Poppy_Humanoid.URDF, servo_mapping.json]
2026-04-28 Add PicoDriver implementation and firmware for Spark tier
    Implements the Pi Pico W driver with MicroPython firmware for
    servo control over WiFi. Updates robot.py and documentation to
    reflect the new hardware interface.
2026-04-28 Redesign skeleton as standalone frame with magnetic shell interface
    Major architecture shift: skeleton is now a complete standalone robot
    frame (200mm, 5-DOF) with 40 magnet seats for snap-on cosmetic shells.
    Replaces the old "subtract skeleton from sculpture" model.
    New specs:
    - SKELETON_SPEC.md: pure mechanical frame design (servos, magnets, wiring)
    - INTERFACE_SPEC.md: contract between skeleton and shells (cut planes,
    clearances, magnet selection algorithm)
    - SHELL_PIPELINE_SPEC.md: customer workflow (design → dissect → hollow →
    magnet bosses → print)
    - SOLIDWORKS_BUILD_GUIDE.md: parametric build guide with equations
    CadQuery script generates high-fidelity STEP with servo-sh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
    [magnet_6x3_reference.step, mg90s_reference.step, sg90_reference.step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]
2026-04-29 Add shell pipeline modules and project reference docs
    Pipeline modules (dissect, hollow, magnets, validate) implement the
    full character→shell workflow: slice mesh into 5 body zones, hollow
    each into a printable shell, select optimal magnet positions, merge
    boss geometry, and validate for 3D printing.
    Updated skeleton.py to 200mm frame with structured data classes for
    servo mounts, magnet seats, cut planes, and clearance envelopes.
    Added docs/SAVE_STATE.md (full project audit reference) and
    docs/NEXT_TASK.md (ordered roadmap of upcoming work).
    [dissect.py, hollow.py, magnets.py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]
2026-04-29 Add 3D generation API wrapper and pricing document
    generate_3d.py wraps Tripo3D (primary) and Meshy (fallback) APIs
    for image-to-3D and text-to-3D generation with automatic failover.
    PRICING.md defines full cost structure: BOM ($17-24), shell printing
    ($2-13), 3D generation ($0.30), shipping ($5). Starter kit at $79-99
    with 51-70% gross margin depending on scale.
    [generate_3d.py]
2026-04-29 Rework shell hollowing to skeleton subtraction + update pricing model
    hollow.py now uses boolean subtraction of skeleton clearance volumes
    instead of fragile vertex-offset hollowing. Results: all shells are
    watertight, torso properly splits into front/back clamshell halves,
    arms have correct volume. Added removal direction specs with draft
    taper angles for easy shell on/off.
    Pricing updated: AI tutor bundled into kit (6mo) and character
    purchases (+6mo each), no separate subscription. Credit packs
    ($4.99-$39.99) for additional AI usage beyond included periods.
    [hollow.py, shell_pipeline.py, skeleton.py]
2026-04-29 Add expanded credit usage: AI skills + animations, not just tutoring
    Credits now power both coding tutor interactions AND action figure
    capabilities like custom animations, character behaviors, movement
    patterns, and personality generation.
2026-04-29 Update all docs to reflect subtraction hollowing, T-pose, pricing model
    SAVE_STATE.md: Added skeleton subtraction, clamshell torso, T-pose
    standard, generate_3d.py, bundled pricing, Fortnite-style credits,
    E2E test results, updated file inventory and decision log.
    NEXT_TASK.md: Marked completed tasks, added T-pose enforcement and
    pipeline tuning tasks, credit store task, updated decision log.
    SHELL_PIPELINE_SPEC.md: Updated to 200mm dimensions, T-pose
    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
2026-04-29 Add T-pose enforcement to 3D generation and dissection
    generate_3d.py: All text-to-3D prompts get T-pose suffix appended
    automatically. Image-to-3D calls include T-pose text guidance.
    Skips injection if prompt already mentions T-pose.
    dissect.py: New validate_tpose() checks arm zone width at shoulder
    height (need >= 15mm), plus width-to-height ratio. Tested against
    Naruto mesh: correctly detects arms-down pose (3.5mm arm zones,
    49mm wide vs 175mm tall).
    [dissect.py, generate_3d.py]
2026-04-30 Add T-pose validation + text-only fallback to image generation
    generate_from_image() now runs a two-pass strategy:
    1. Image-to-3D with T-pose text guidance
    2. Validate result with validate_tpose() (arm width + proportions)
    3. If not T-pose → retry as text-only using character description
    (image overpowered the guidance, so drop it for geometry)
    Includes _describe_image_for_text_fallback() placeholder — in
    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
2026-04-30 Update all docs with T-pose two-pass strategy and current state
    SAVE_STATE.md: Updated generate_3d.py description, expanded T-pose
    section with two-pass fallback details, validation thresholds, and
    test results against Naruto mesh.
    NEXT_TASK.md: Marked T-pose tasks complete, added vision model
    fallback TODO, updated completed tasks table and decision log.
    SHELL_PIPELINE_SPEC.md: Updated Step 4 with T-pose enforcement
    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
2026-04-30 Add full component reference guide and 250mm equations
    COMPONENT_REFERENCE.md: Every component in the Pro skeleton with exact
    dimensions, mounting holes, pocket sizes, clearances, CAD download links.
    Covers: SG90, MG90S, XL330 Dynamixel, STS3215, Pi 5/Zero 2W/Pico W,
    PCA9685, MAX98357A amp, speaker, INMP441 mic, MPU6050 IMU, HC-SR04
    ultrasonic, NeoPixel LEDs, TP4056 charger, LiPo battery, USB-C breakout.
    equations_250mm.txt: All parametric variables for the 250mm Pro skeleton
    including servo positions, component dimensions, pocket sizes with
    clearances for all three servo types.
2026-04-30 Update component reference with confirmed servo specs and CAD links
    XL330: confirmed GrabCAD STEP link, added datasheet reference.
    STS3215: corrected dimensions to 45.2×24.7×35mm (from research),
    added official datasheet PDF link and GrabCAD STEP.
    Confirms XL330 is right choice for 250mm legs (STS3215 too large).
2026-04-30 Rewrite build guide as kinematic skeleton assembly (SSP method)
    Complete SolidWorks 2025 guide using Skeleton Sketch Part approach:
    1. Create SSP with construction lines for all 17 DOF kinematic chain
    2. 18 reference planes + 18 reference axes for every joint
    3. ~25 reference points for electronics/sensor placement
    4. Place servos with concentric + coincident mates to SSP axes
    5. Limit mates for joint range constraints
    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
2026-04-30 Add SolidWorks VBA macro to build complete kinematic SSP
    hawabot_ssp_macro.bas creates the full Skeleton Sketch Part in one
    click: 70+ global variables, 18 reference planes at each joint,
    18 reference axes for rotations, and a 3D construction line sketch
    showing the complete kinematic chain (spine, arms, legs, base).
    Usage: New Part → Tools → Macro → New → Import this .bas file → Run
2026-05-11 Restructure to two-tier strategy (Spark + Pro) with full documentation overhaul
    - Eliminate Core tier. Two tiers at launch: Spark ($199, 7 DOF desk companion)
    and Pro ($599, 19 DOF walking humanoid). Max ($999+) is future flagship.
    - Spark and Pro share same 250mm skeleton and ESP32-S3 custom PCB.
    - Pro adds legs (8x XL330), elbows, hands, FSRs, IMU, mic, camera, battery.
    - Pro walks (FSRs in feet required, confirmed from Poppy research).
    - Max is aspirational 400-500mm robot with on-board AI for graduates.
    Files changed:
    - CLAUDE.md: Created — project conventions, tech stack, tier architecture
    - hawabot/config/tiers.py: Two tiers (Spark/Pro/Max), correct DOF/servos/MCU
    - docs/ARCHITECT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
    [hawabot_skeleton_sketch.SLDPRT, magnet_6x3_reference.step, mg90s_reference.step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]
2026-05-11 Add prototype BOM checklist with Phase 1 (Spark) and Phase 2 (Pro) parts
    Phase 1 ordered ($61): ESP32-S3 DevKitC-1, HiLetgo PCA9685 2-pack,
    5x SG90, 2x MG90S, MAX98357A amp, speaker, breadboard, wires, PSU.
    Phase 2 deferred ($322): 8x XL330, arm servos, sensors, battery.
    Includes full wiring diagrams, channel allocation, and custom PCB
    reference showing breakout-to-IC mapping for future KiCad design.
2026-05-11 docs: replace breadboard with soldered prototype approach in BOM
    Phase 1 total updated from $61 to $56. Removed breadboard and jumper
    wires, replaced with hookup wire and solder supplies.
2026-05-12 docs: add full tier component reference (Spark, Pro, Max)
    Complete component tables with quantities, interfaces, and intent
    for all three tiers. Includes servo allocations and side-by-side
    comparison.
2026-05-12 docs: comprehensive strategy update — remove Core tier, align all docs
    Updated all strategy docs to reflect two-tier architecture:
    - Spark ($199, 7 DOF) + Pro ($599, 19 DOF) + Max ($999+, future)
    - Removed all Core tier references across 6 docs
    - Updated pricing, DOF counts, servo types, compute platform
    - Added TonyPi to competitive analysis
    - Added SolidWorks cowork context doc for CAD sessions
    - Updated stale audit with all resolved items
    Files updated: ARCHITECTURE.md, COMPETITIVE_ANALYSIS.md,
    GO_TO_MARKET.md, IMPLEMENTATION_PLAN.md, STALE_AUDIT.md,
    PARAMETRIC_PIPELINE_PLAN.md
    New: SOLIDWORKS_CONTEXT.md (cowork reference)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
2026-05-24 docs: full staleness audit — fix Core refs, update MCU/servo specs across pipeline docs
    - COMPONENT_REFERENCE: remove Core tier, update MCU to ESP32-S3, fix servo counts, remove waist roll/LEDs/ultrasonic
    - SOLIDWORKS_BUILD_GUIDE: replace Pi 5 with ESP32-S3 PCB, add shoulder roll, remove waist roll, update assembly tree
    - pi5.py: change Pro→Max tier in docstrings, remove Core references
    - INTERFACE_SPEC: Pico USB→ESP32-S3 USB-C
    - SKELETON_SPEC: Core Humanoid→Max Humanoid
    - IMPLEMENTATION_PLAN: mark Core tier tech debt as resolved
    - GO_TO_MARKET: update partnership compute platforms
    - ARCHITECTURE: add ESP32Driver to driver list
    - STALE_AUDIT: log all fixes from 2026-05-24
    Co-Authore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
    [pi5.py]
2026-05-24 docs: standardize MCU to ESP32-S3-WROOM-1-N16R8 (16MB flash, 8MB PSRAM)
    N16R8 selected for maximum headroom: 16MB flash for OTA A/B partitions
    and future features, 8MB PSRAM required for Pro camera frame buffering.
    Same module across Spark and Pro (one PCB design).
    Updated 7 files: CLAUDE.md, TIER_COMPONENTS, PROTOTYPE_BOM_CHECKLIST,
    COMPONENT_REFERENCE, SOLIDWORKS_BUILD_GUIDE, SOLIDWORKS_CONTEXT,
    PARAMETRIC_PIPELINE_PLAN.
2026-05-25 docs: add ESP32-S3-DevKitC-1-N16R8 to prototype BOM
    Matches production module (16MB flash, 8MB PSRAM). Updated LDO to
    AP2112K-3.3 (proven on Aerwyz Pod), PCB size to 60x40mm.
2026-05-25 feat: switch mic to SPH0641LU4H-1 (PDM), add KiCad libs + datasheets
    INMP441 (I2S) unavailable at LCSC. Replaced with SPH0641LU4H-1
    (Knowles PDM MEMS mic, LCSC C2879853, $1.21, ~2400 in stock).
    Same mic used on Aerwyz Pod — proven on ESP32-S3 with hardware PDM.
    Frees one GPIO pin (PDM needs 2 vs I2S needs 3).
    Added:
    - 11 datasheets (7 copied from Pod, 4 new: PCA9685, MAX98357A, MPU6050, OV2640)
    - 4 KiCad symbol/footprint libraries from Pod (SPH0641, TP4056, DW01A, FS8205A)
    Full BOM audited against LCSC — all components in stock, no blockers.
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2026-05-25 fix: schematic guide v1.1 — fix all audit findings (5 critical, 8 high)
    Critical fixes:
    - PCA9685 TSSOP-28: corrected ALL pin numbers (SDA=27, SCL=26, A0-A4=1-5,
    A5=24, OE=23). Previous version had wrong pins that would short 5V to I2C.
    - Removed crystal (Y1) — PCA9685 has no OSC pins, uses internal 25MHz
    - Removed "VSERVO" from IC — bare PCA9685 has no servo power pin.
    Servo 5V goes directly to header power pins, not through IC.
    High fixes:
    - Moved FSR_RF from GPIO3 (strapping pin) to GPIO11
    - Moved FSR_RR from GPIO10 (camera conflict) to GPIO12
    - Added MPU6050 VLOGIC pin connection to +3V3
    - Added MPU6050 charge pump capacitor (C19)
    - Camera DVP reassigned to avoid GPIO35-37 (PS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
2026-05-25 feat: schematic guide v1.2 — add boost converter, OR-ing, status LED
    New steps added:
    - Step 8b: WS2812B RGB status LED (GPIO48) + green power LED on +3V3
    - Step 13b: TPS61023 boost converter (VBAT 3.7V → 5.1V, LCSC C919459)
    - Step 13c: OR-ing Schottky diodes (USB 5V + boost 5.1V → +5V_SERVO)
    Design decisions resolved:
    - Single-cell LiPo + boost (not 2S + buck): reuses Pod TP4056/DW01A
    circuit, safer for kids, proven design
    - WS2812B RGB LED for multi-color status (boot/WiFi/error/OTA)
    - TPS61023: 3.7A peak, SOT-563, $0.14 on LCSC
    Power architecture updated:
    - USB and battery feed through OR-ing diodes to +5V_SERVO
    - Seamless switchover: unplug USB → battery takes over
    - LDO inpu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
2026-05-25 fix: schematic guide v1.3 — fix all second audit findings
    Critical fixes (4):
    - TPS61023 pin numbers corrected (1=FB, 2=EN, 3=VIN, 4=GND, 5=SW, 6=VOUT)
    - Removed external Schottky D_BOOST (TPS61023 is synchronous, has internal rectifier)
    - Inductor changed from 2.2µH to 1µH per TI recommendation (Table 8-2)
    - Topology diagram redrawn for synchronous boost (no external diode)
    High fixes (5):
    - VREF corrected from 0.5V to 0.595V, R17 from 920k to 750k → Vout=5.06V
    (920k would have produced dangerous 6V output above OVP threshold)
    - LDO input (Step 2) changed from +5V to +5V_SERVO for battery operation
    - DW01A pin 2 name corrected from CS to VM
    - FSR GPIOs moved to all-ADC1 (GPIO1,2,3,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
2026-05-25 fix: schematic guide v1.3 final cleanup — third audit pass clean
    All critical and high issues resolved in prior commits. This fixes
    remaining medium/low items from third audit:
    - Step 13b header: 7→6 components (no external Schottky)
    - Step 3 header: 5→6 components (includes SW2 reset button)
    - Step 18 verify: fixed stale GPIO10/camera D0 cross-reference
    - SS34 Vf: corrected max from 0.85V to 0.70V per datasheet
    - Boost output: clarified 1.5A continuous (2A+ burst) per TI spec
    - Board size: aligned all docs to 60x40mm (was 55x35mm in 5 files)
    Third audit result: NO CRITICAL ISSUES. Ready for KiCad entry.
2026-05-28 feat: enforce T-pose with leg separation across all generation paths
    - Wire T-pose prompt enforcement into web/app.py Meshy calls (was bypassed)
    - Add TPOSE_IMAGE_GUIDANCE to image-to-3D API calls
    - Add early T-pose validation gate in web API — rejects bad models before pipeline runs
    - Add leg separation check to validate_tpose() — detects fused legs at mid-thigh
    - Strengthen prompt text to explicitly require separated legs with visible gap
    [dissect.py, generate_3d.py]
2026-05-29 feat: update skeleton.py + hollow.py to 250mm v17 geometry (19 DOF)
    - Update all coordinates from 200mm to 250mm v17: shoulders Z=140,
    head pan Z=155, tilt Z=185, waist Z=15, elbow Z=100, hip Z=0,
    knee Z=-55, ankle Z=-110
    - Add XL330 servo spec (20×34×26mm) for Pro shoulders/waist/legs
    - Expand servo mounts from 5 to 19 with tier field (spark/pro)
    - Add leg body zones, cut planes, magnet seats, clearance envelopes
    - Add leg clearance volume builder with XL330 housings and sweeps
    - Update torso/arm/base clearance builders for v17 coordinates
    - Add backward-compatible aliases (SHOULDER_SPREAD, HEAD_Z, etc.)
    [hollow.py, skeleton.py]
2026-05-29 feat: align skeleton + hollow to STEP v1 mockup geometry
    Parsed subtract_skeleton_ref.STEP from SolidWorks to extract actual
    component positions. Updated servo types (XL330 → MG90S at shoulders
    and waist), arm layout (horizontal at Z=140 from X=±74 to X=±164),
    torso/base cut (Z=5 → Z=12 at frame_chest bottom), and all downstream
    constants, clearance volumes, magnet seats, and joint sweeps.
    [hollow.py, skeleton.py]
2026-05-29 feat: character-adaptive dissection + SkeletonSpec variants
    Dissection now derives cut planes from the character's own detected
    landmarks (neck pinch, shoulder line, armpit, hip/crotch) instead of the
    skeleton's fixed joint positions, so any T-pose body — humanoid, animal,
    creature — dissects correctly. dissect_character(cut_planes=None) triggers
    detection; explicit planes still override.
    - pipeline/landmarks.py: landmark detection + adaptive_cut_planes()
    - pipeline/dissect.py: wire adaptive cuts as the default path
    - pipeline/skeleton.py: SkeletonSpec holds per-variant dimensions (variable
    parts) while servo pockets/fixtures stay standard; convenience constants now
    derive from DEFA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
    [check_alignment.py, dissect.py, landmarks.py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]
